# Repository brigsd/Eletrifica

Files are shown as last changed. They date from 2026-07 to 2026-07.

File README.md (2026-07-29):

# Controladora CNC / Laser com ESP32

> ### ▶ [**Abrir o visualizador 3D interativo**](https://brigsd.github.io/Eletrifica/)
> Gire a placa, oculte as peças que quiser pelo menu lateral e **dê dois cliques
> em qualquer componente** para ver o que ele faz e em quais nets ele está ligado.

Este repositório é a **engenharia reversa completa de uma placa de circuito
impresso**, feita a partir do único material disponível: o pacote Gerber que se
manda para a fábrica.

A placa é uma **controladora de CNC / gravadora a laser de dois eixos**: um
módulo ESP32 comanda dois drivers de passo A4988 e chaveia um laser por um
MOSFET. São 70,5 × 54,6 mm, duas camadas, 19 componentes e 43 nets.

Partindo só do Gerber, foram reconstruídos:

| | |
|---|---|
| **Netlist** | Todas as 43 ligações, conferidas por dois métodos independentes |
| **Esquemático** | Projeto KiCad que abre e edita, gerado por script a partir da netlist |
| **Layout** | Desenho das trilhas, pads e serigrafia das duas faces |
| **Modelo 3D** | A placa montada, com cada peça posicionada pelo Gerber |
| **Visualizador** | A página interativa publicada no GitHub Pages |
| **Análise** | Como o circuito funciona — e um defeito que ele tem |

E, no meio do caminho, **dois problemas apareceram** — um elétrico e um
mecânico. Ambos estão em [`docs/analise.md`](docs/analise.md).

---

## O visualizador 3D

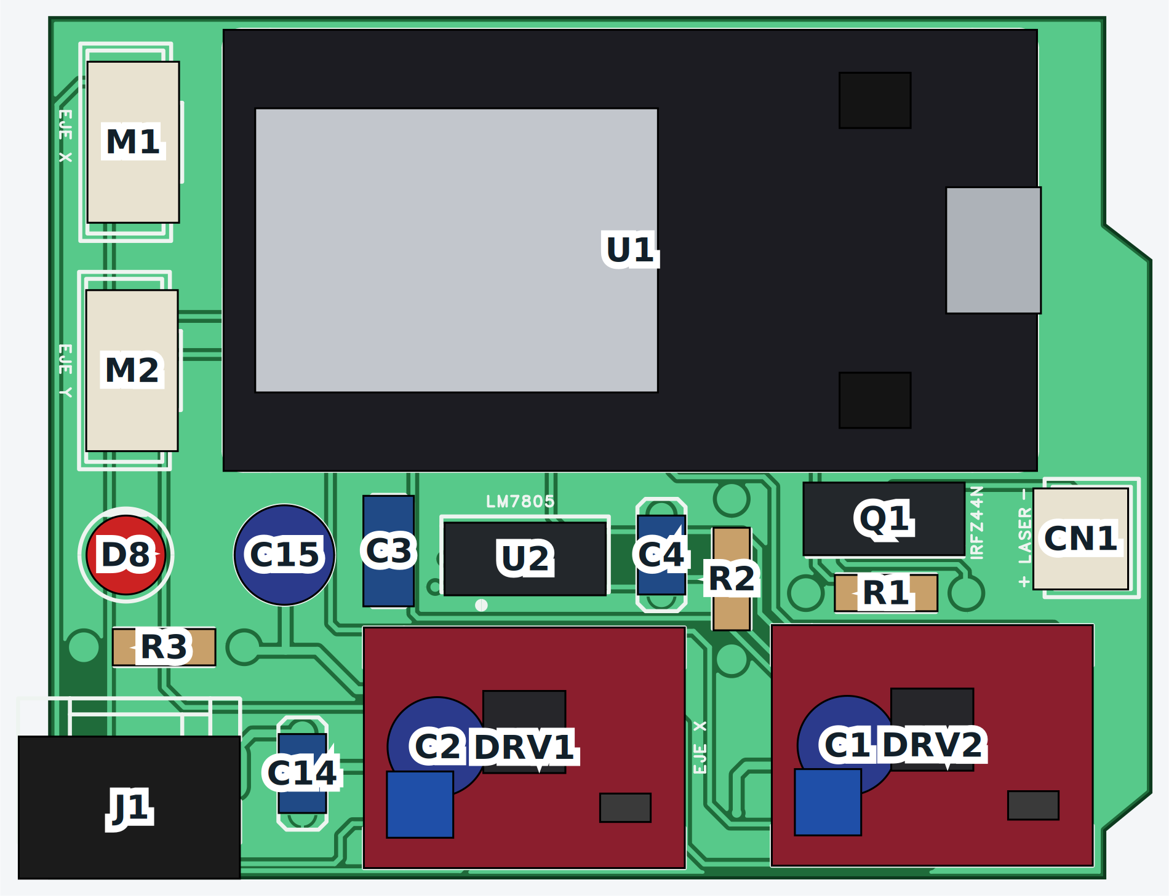
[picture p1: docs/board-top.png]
Visualizador (https://brigsd.github.io/Eletrifica/)


**→ [brigsd.github.io/Eletrifica](https://brigsd.github.io/Eletrifica/)**

- **Menu lateral** — liga e desliga cada peça, ou um grupo inteiro (Controle,
  Eixos, Alimentação, Laser). O botão *Placa* esconde a própria placa, o que
  deixa ver o que fica por baixo dos módulos.
- **Duplo clique numa peça** — abre para que ela serve, com a lista de
  pino → net daquele componente.
- **▲ vermelho** no menu marca as peças envolvidas no conflito de folga.

A página é estática e não depende de nada externo: o Three.js está versionado
em `web/`, junto com a geometria em `web/board.json`, que sai do mesmo modelo
que gera os desenhos impressos.

---

## Layout da placa

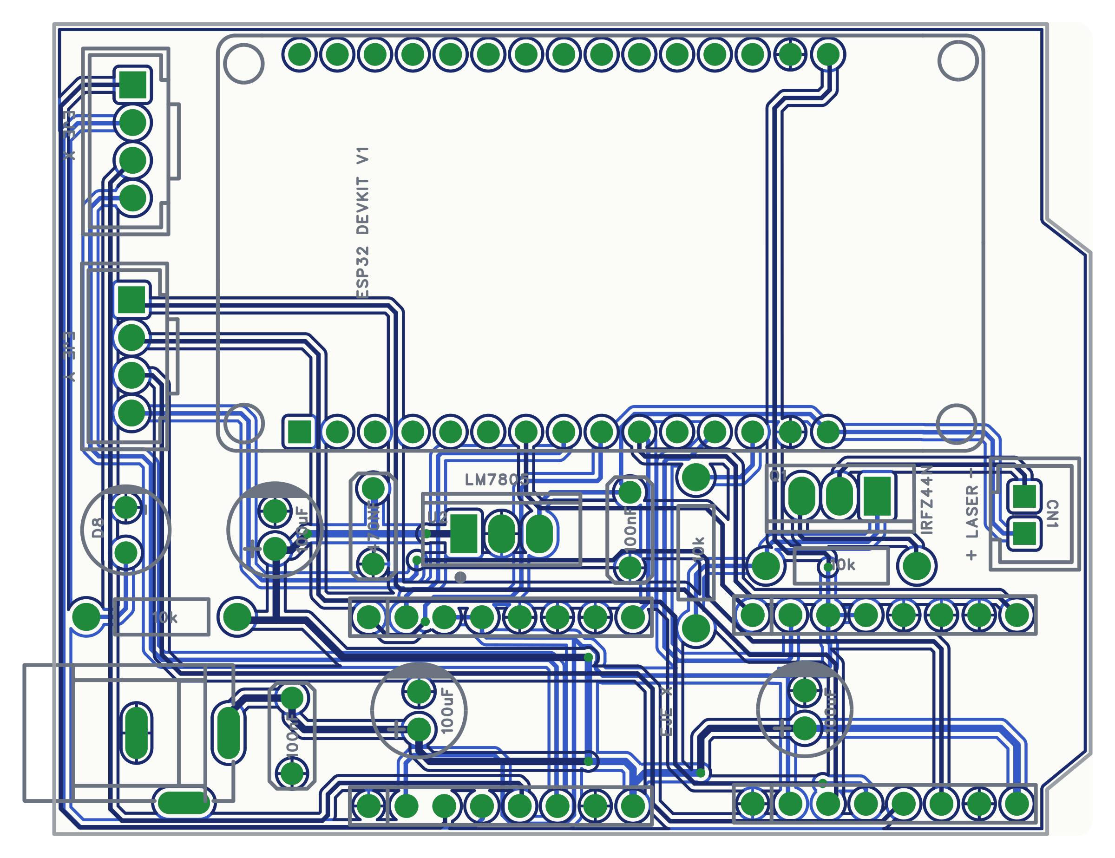
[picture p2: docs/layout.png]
Layout


Trilhas da face superior em azul-escuro, da face inferior em azul-claro, pads em
verde e serigrafia em cinza. Os planos de terra ficam ocultos por padrão para as
trilhas aparecerem; `--pour` desenha eles em tom claro.

```bash
python3 tools/render_layout.py --split    # layout.svg, layout-top.svg, layout-bottom.svg
```

Também são gravados os `.png` correspondentes.

## Vistas 3D

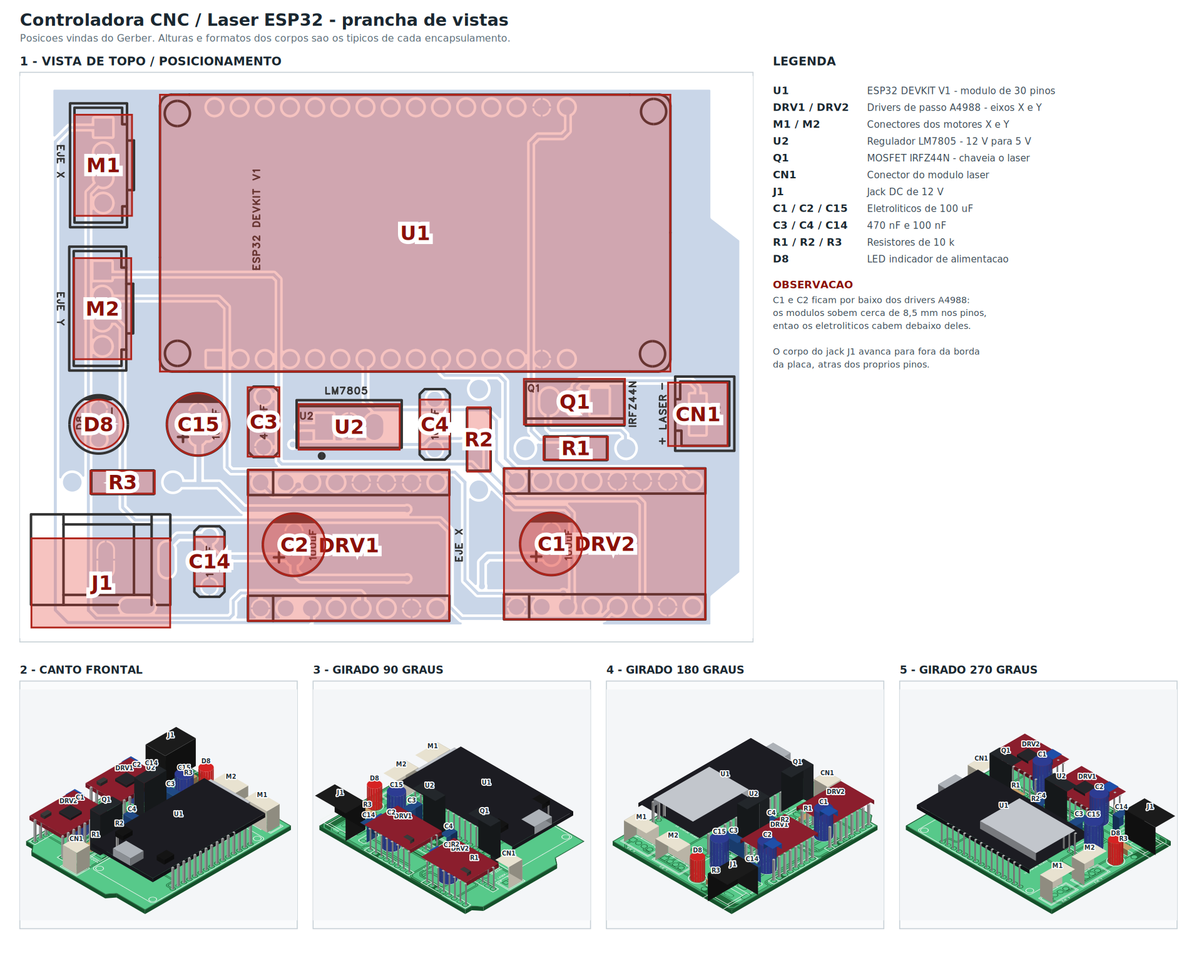
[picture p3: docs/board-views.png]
Prancha de vistas


Vista de topo com os corpos sobre a serigrafia (para conferir posicionamento) e
o mesmo conjunto visto de quatro ângulos.

```bash
python3 tools/render_3d.py --sheet --plan --views --steps
```

### Módulos como peças próprias

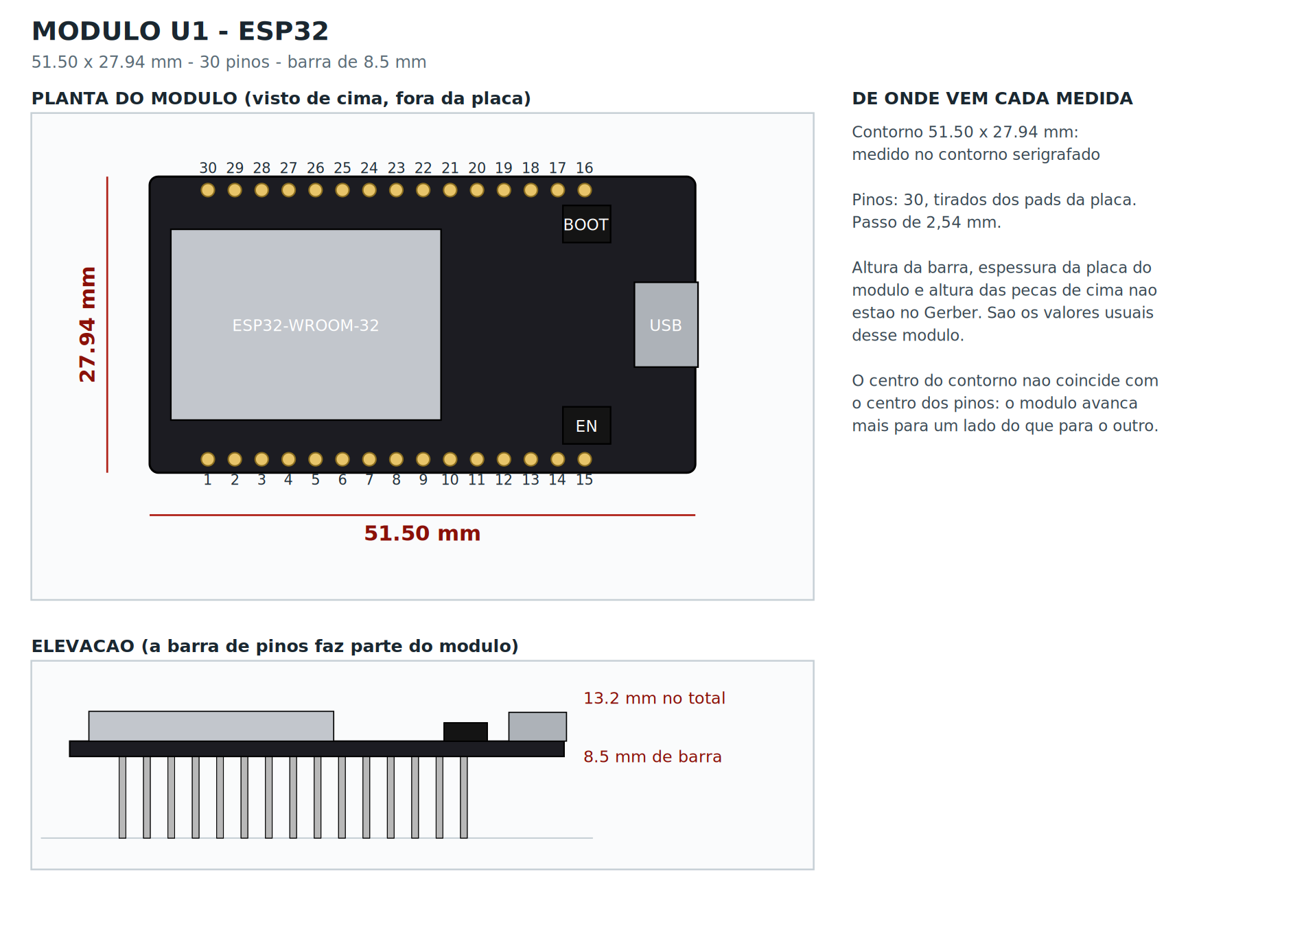
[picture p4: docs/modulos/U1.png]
Módulo ESP32


Os três módulos (ESP32 e os dois A4988) são modelados como peças em si: contorno
próprio, barra de pinos própria e o que fica em cima deles. O contorno do ESP32
**foi medido no desenho que a placa-mãe carrega na serigrafia** para ele —
51,50 × 27,94 mm, que é a medida real do DevKit V1, e cujo centro fica 2,5 mm
deslocado do centro dos pinos. `docs/modulos/` traz uma página por módulo.

Modelar os módulos direito fez aparecer um conflito mecânico: os eletrolíticos
C1 e C2 ficam debaixo dos drivers e, pelas alturas usuais, não passam no vão.
Ver [`docs/analise.md`](docs/analise.md).

### Conferência peça por peça

`--steps` grava `docs/posicionamento/`: uma página por peça, começando pela placa
nua. Cada página mostra a **placa sozinha mais uma única peça**, para conferir a
posição sem as outras atrapalhando — vista de topo sobre a serigrafia, uma
perspectiva, e as **quatro vistas laterais ortográficas** (frente, trás, esquerda,
direita), com a câmera na altura da placa. São **duas vistas de topo**: uma com a
peça sólida, como a placa montada se vê de cima, e outra em raio X sobre a
serigrafia, para conferir se o corpo cai em cima do próprio contorno. Nas laterais a altura sai verdadeira,
coisa que nenhuma vista isométrica dá. As demais peças ficam fantasmas em 12 %
só como referência.

Foi assim que apareceram os dois detalhes anotados na prancha: o eletrolítico
por baixo do driver A4988 e o corpo do jack passando da borda.

As **posições** de todas as peças saem do Gerber, tiradas do centro dos pads de
cada uma. As **alturas e formatos dos corpos não saem do Gerber** — um Gerber não
tem modelo 3D — então são as dimensões típicas de cada encapsulamento, listadas
em `BODIES` no script. O desenho serve para entender a placa, não para
verificação mecânica.

## Esquemático

Esquemático

## O que é a placa

Controladora de **CNC / gravadora a laser de 2 eixos**: um módulo ESP32 DEVKIT V1
comanda dois drivers de passo tipo A4988 (eixos X e Y) e chaveia um laser por um
MOSFET. Alimentação de 12 V com regulação para 5 V por LM7805.

70,5 × 54,6 mm · 2 camadas · 19 componentes · 43 nets

## Arquivos

| Caminho | Conteúdo |
|---|---|
| `hardware/esp32-cnc-laser.kicad_sch` | Esquemático KiCad (abre no KiCad 7+) |
| `hardware/esp32-cnc-laser.kicad_pro` | Projeto KiCad |
| `docs/board-views.svg` · `.png` | Prancha: topo + quatro ângulos |
| `docs/board-top.svg` · `.png` | Vista de topo com as peças sólidas |
| `docs/board-plan-check.*` | Vista de topo em raio X sobre a serigrafia |
| `docs/posicionamento/` | Uma página por peça: 2 topos, perspectiva e 4 laterais |
| `docs/modulos/` | Uma página por módulo, com as medidas e a pinagem |
| `docs/board-3d-000/090/180/270.*` | Cada ângulo separado |
| `docs/layout.svg` · `.png` | Desenho do layout (as duas faces) |
| `docs/layout-top.*` · `layout-bottom.*` | Layout de cada face separadamente |
| `docs/esp32-cnc-laser.svg` · `.pdf` | Esquemático renderizado |
| `docs/analise.md` | Como o circuito funciona e o que há de errado nele |
| `docs/bom.md` | Lista de materiais |
| `docs/netlist.md` | Tabela de todos os nets |
| `index.html` · `web/` | O visualizador 3D publicado no GitHub Pages |
| `gerber/` | Pacote Gerber original, que é a fonte de tudo |
| `THIRD_PARTY.md` | Código de terceiros no repositório, com versão e licença |
| `tools/` | Scripts que geram e conferem o esquemático |

## De onde veio cada informação

**As conexões** vêm de `gerber/FlyingProbeTesting.json`, um arquivo do pacote
Gerber que lista o net de cada pad da placa. Nada de conectividade foi inferido.

**Os valores e part numbers** foram lidos da serigrafia
(`gerber/Gerber_TopSilkscreenLayer.GTO`), renderizada a partir do Gerber.

**A pinagem** dos módulos ESP32 e A4988 foi deduzida da netlist e confere com a
pinagem padrão desses módulos em todas as 30 e 16 ligações.

## Como isso foi verificado

O esquemático não é um desenho "que parece certo" — ele é conferido por duas
verificações automáticas:

```bash
python3 tools/verify_netlist.py   # esquemático  x  netlist da placa
python3 tools/check_copper.py     # geometria do cobre  x  netlist da placa
```

**`verify_netlist.py`** exporta a netlist do `.kicad_sch` com o `kicad-cli` e
compara net a net com a da placa. Resultado atual: **22 de 22 nets idênticos**,
sem sobra nem falta.

**`check_copper.py`** é independente do arquivo de netlist: rasteriza as duas
camadas de cobre usando as aberturas do próprio Gerber, rotula as ilhas de cobre
conectadas e une as faces nos furos metalizados e nas 9 vias. Ele só usa
coordenadas, nunca nomes de net. Resultado atual: **43 ilhas para os 43 nets, com
0 falsos cortes e 0 falsos curtos**.

## Um defeito encontrado na placa

O **source do Q1 (IRFZ44N) não chega ao GND** em nenhuma das duas camadas. O net
tem só dois pads: o pino 3 do Q1 e o pino 1 do R1. Sem esse retorno o MOSFET não
conduz e **o laser nunca acende**, independente do firmware.

Os dois métodos de verificação acima concordam nisso. Detalhes e as demais
observações de projeto em [`docs/analise.md`](docs/analise.md).

## Regenerar

Precisa de KiCad 7+ (`kicad-cli`) e das dependências em `requirements.txt`.

```bash
pip install -r requirements.txt

python3 tools/render_layout.py --split   # desenhos do layout
python3 tools/export_web.py         # dados do visualizador 3D
python3 tools/gen_schematic.py      # escreve hardware/esp32-cnc-laser.kicad_sch
python3 tools/gen_docs.py           # escreve docs/bom.md e docs/netlist.md
kicad-cli sch export svg --output docs hardware/esp32-cnc-laser.kicad_sch
kicad-cli sch export pdf --output docs/esp32-cnc-laser.pdf hardware/esp32-cnc-laser.kicad_sch
```

O esquemático é **gerado** a partir do Gerber, não desenhado à mão:
`gen_schematic.py` lê a netlist da placa e emite o `.kicad_sch`. Corrigir a placa
é mudar o Gerber e rodar de novo.

## Código de terceiros

Duas coisas aqui não são deste projeto: o **three.js** (MIT), versionado em
`web/` para o visualizador não depender de CDN, e **doze símbolos do KiCad**
(CC-BY-SA 4.0 com exceção), embutidos no `.kicad_sch` para ele abrir em
qualquer máquina. Detalhes e textos de licença em
[`THIRD_PARTY.md`](THIRD_PARTY.md).

## Licença

**MIT** — ver [`LICENSE`](LICENSE).

Cobre o que foi criado aqui: os scripts, o visualizador, os desenhos e a
documentação. **Não cobre o `gerber/`**, que é o projeto original da placa e
pertence a quem a desenhou — ele está aqui como material de origem da
engenharia reversa.

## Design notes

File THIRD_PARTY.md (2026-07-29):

# Código de terceiros

Duas coisas neste repositório não são deste projeto: a biblioteca 3D usada pelo
visualizador e alguns símbolos de esquemático do KiCad. Estão listadas aqui com
a versão e a licença de cada uma.

As bibliotecas Python usadas pelos scripts (`gerbonara`, `cairosvg`, `numpy`,
`scipy`, `pillow`) **não** estão no repositório — vêm por `pip` a partir do
`requirements.txt` e não foram copiadas para cá.

---

## 1. three.js — em `web/`

| | |
|---|---|
| Projeto | [three.js](https://threejs.org/) |
| Versão | r128 (`three@0.128.0`) |
| Arquivos | `web/three.min.js` · `web/OrbitControls.js` |
| Licença | MIT |

`OrbitControls.js` vem de `examples/js/controls/` do mesmo pacote.

**Por que está versionado aqui em vez de vir de CDN:** a página não busca nada
de fora. Não quebra se um CDN sair do ar ou mudar de política, funciona offline,
e o que foi testado é exatamente o que vai para o ar.

### Licença MIT

```
The MIT License

Copyright © 2010-2021 three.js authors

Permission is hereby granted, free of charge, to any person obtaining a copy
of this software and associated documentation files (the "Software"), to deal
in the Software without restriction, including without limitation the rights
to use, copy, modify, merge, publish, distribute, sublicense, and/or sell
copies of the Software, and to permit persons to whom the Software is
furnished to do so, subject to the following conditions:

The above copyright notice and this permission notice shall be included in
all copies or substantial portions of the Software.

THE SOFTWARE IS PROVIDED "AS IS", WITHOUT WARRANTY OF ANY KIND, EXPRESS OR
IMPLIED, INCLUDING BUT NOT LIMITED TO THE WARRANTIES OF MERCHANTABILITY,
FITNESS FOR A PARTICULAR PURPOSE AND NONINFRINGEMENT. IN NO EVENT SHALL THE
AUTHORS OR COPYRIGHT HOLDERS BE LIABLE FOR ANY CLAIM, DAMAGES OR OTHER
LIABILITY, WHETHER IN AN ACTION OF CONTRACT, TORT OR OTHERWISE, ARISING FROM,
OUT OF OR IN CONNECTION WITH THE SOFTWARE OR THE USE OR OTHER DEALINGS IN
THE SOFTWARE.
```

---

## 2. Símbolos do KiCad — dentro de `hardware/esp32-cnc-laser.kicad_sch`

| | |
|---|---|
| Projeto | [KiCad Symbols](https://kicad.github.io/symbols/) |
| Copyright | KiCad Community |
| Licença | CC-BY-SA 4.0 **com exceção** (texto abaixo) |

Um arquivo `.kicad_sch` sempre carrega dentro de si a definição dos símbolos que
usa, na seção `lib_symbols`. `tools/gen_schematic.py` copia essas definições da
instalação local do KiCad para o arquivo gerado — é o que faz o esquemático
abrir em qualquer máquina, sem depender de quais bibliotecas estão instaladas.

**Doze símbolos vêm do KiCad:**

`Device:R` · `Device:C` · `Device:C_Polarized` · `Device:LED` ·
`Device:Q_NMOS_GDS` · `Regulator_Linear:LM7805_TO220` ·
`Connector_Generic:Conn_01x02` · `Conn_01x03` · `Conn_01x04` ·
`power:+12V` · `power:+5V` · `power:GND`

**Dois foram desenhados para este projeto**, porque não existem na biblioteca do
KiCad — são gerados por `rect_symbol()` em `tools/gen_schematic.py`:

`Module:ESP32_DEVKIT_V1` (30 pinos) · `Module:A4988` (16 pinos)

### A exceção da licença

A CC-BY-SA normalmente exigiria que trabalhos derivados fossem publicados sob a
mesma licença. A biblioteca do KiCad traz uma renúncia explícita a isso para
projetos eletrônicos:

> To the extent that the creation of electronic designs that use 'Licensed
> Material' can be considered to be 'Adapted Material', then the copyright
> holder waives article 3 of the license with respect to these designs and any
> generated files which use data provided as part of the 'Licensed Material'.

Ou seja: usar esses símbolos **não obriga** este projeto a adotar CC-BY-SA.

---

## Licença deste projeto

**MIT** — ver [`LICENSE`](LICENSE).

Ela cobre o que foi criado aqui: os scripts em `tools/`, o visualizador, e os
desenhos e documentos gerados em `docs/` e `hardware/`.

**Não cobre o `gerber/`.** Aquele pacote é o projeto original da placa e
pertence a quem a desenhou — está no repositório como material de origem da
engenharia reversa. O `LICENSE` diz isso explicitamente.

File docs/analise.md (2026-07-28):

# Análise do circuito

Placa: **controladora CNC / gravadora a laser de 2 eixos com ESP32**, dupla face,
70,5 × 54,6 mm, 19 componentes, 43 nets.

---

## Como o circuito funciona

### 1. Entrada e regulação

O jack `DC_CARGADOR` traz **12 V**, que alimentam diretamente o `VMOT` dos dois
drivers de passo. O trilho de 12 V tem três eletrolíticos de 100 µF (C1, C2, C15)
e um cerâmico de 100 nF (C14).

O **LM7805** (U2) derruba 12 V para **5 V**, com C3 (470 nF) na entrada e C4
(100 nF) na saída. O trilho de 5 V alimenta o `VIN` do ESP32 e o positivo do laser.

O **3,3 V** não é gerado na placa: sai do regulador interno do próprio módulo
ESP32 (pino 3V3) e alimenta o `VDD` lógico dos dois drivers.

`D8` + `R3` (10 k) formam o indicador de alimentação, ligado no trilho de 12 V.

### 2. Controle

O **ESP32 DEVKIT V1** usa 6 dos seus 30 pinos:

| Pino | GPIO | Sinal |
|---|---|---|
| 8  | GPIO25 | `STEP` — eixo X |
| 9  | GPIO26 | `DIR` — eixo X |
| 12 | GPIO12 | `STEP_2` — eixo Y |
| 7  | GPIO33 | `DIR_2` — eixo Y |
| 10 | GPIO27 | `EN` — habilita **os dois** drivers |
| 13 | GPIO13 | PWM do laser |

Os outros 24 pinos ficam sem ligação.

### 3. Drivers de passo

Dois módulos de 16 pinos tipo **A4988**, um por eixo. A configuração é idêntica
nos dois e foi lida da netlist:

- `MS1`, `MS2`, `MS3` → **GND** ⇒ modo **passo inteiro**, sem micropasso
- `RESET` + `SLEEP` → **3,3 V** ⇒ driver habilitado (ligação padrão)
- `VMOT` → 12 V, `VDD` → 3,3 V
- Bobinas `1A`/`1B` e `2A`/`2B` vão para os conectores `EJE X` e `EJE Y`

### 4. Saída do laser

`GPIO13` → `R2` (10 k) → gate do **IRFZ44N** (Q1). `R1` (10 k) liga o gate ao
source. O dreno do Q1 é o `LASER_NEG`, que vai ao pino 1 do `CN1`; o pino 2 do
`CN1` é o **+5 V**. Ou seja, o laser é alimentado em 5 V e o MOSFET chaveia o
lado negativo.

---

## Achados

### 🔴 1. O source do Q1 não tem retorno para o GND

**Este é um defeito de projeto da placa, não do esquemático.**

O net do source do Q1 (chamado `$1N1796` no arquivo original, renomeado aqui para
`SRC_Q1`) contém **exatamente dois pads**: `Q1` pino 3 e `R1` pino 1. Ele não
toca o GND em nenhuma das duas camadas de cobre, nem através de via.

Sem esse retorno o IRFZ44N não tem circuito de dreno-source fechado: **o laser
nunca acende**, independentemente do que o firmware faça com o GPIO13.

Isso foi verificado por dois caminhos independentes, que concordam:

1. **`FlyingProbeTesting.json`** — o arquivo de teste que acompanha o Gerber,
   gerado pelo CAM a partir da placa, lista o net de cada pad. `SRC_Q1` tem 2 pads.
2. **Geometria do cobre** (`tools/check_copper.py`) — rasteriza as duas camadas
   a partir das aberturas do Gerber, rotula as ilhas de cobre conectadas e une as
   faces nos furos metalizados e nas 9 vias. Esse método **não lê nenhum nome de
   net**, só coordenadas. Resultado: 43 ilhas para os 43 nets da placa, com
   **0 falsos cortes e 0 falsos curtos**, e a ilha do `Q1` pino 3 contém apenas
   `Q1_3` e `R1_1`.

Como o segundo método reproduz a netlist inteira sem um único erro, o resultado
sobre o `SRC_Q1` tem o mesmo grau de confiança que o resto da netlist.

**Correção:** ligar o pino 3 (source) do Q1 ao GND.

> Vale confirmar com um multímetro em modo continuidade entre o pino 3 do Q1 e
> qualquer ponto de GND antes de alterar a placa — é um teste de 10 segundos.

### 🟡 2. O IRFZ44N não é um MOSFET de nível lógico

Observação de datasheet, não da netlist. O IRFZ44N tem `Vgs(th)` entre 2,0 e
4,0 V e o `Rds(on)` de 17,5 mΩ é especificado com **`Vgs` = 10 V**. Acionado pelos
3,3 V de um GPIO do ESP32, ele opera perto do limiar: conduz pouco e esquenta.

Mesmo depois de corrigir o problema 1, vale trocar por um MOSFET de nível lógico
(IRLZ44N, IRL540N, AOD4184) ou acrescentar um driver de gate.

### 🟡 3. R2 = 10 k em série com o gate

O IRFZ44N tem cerca de 1,5 nF de capacitância de entrada. Com 10 k em série a
constante de tempo fica na casa de 15 µs. Serve para ligar/desligar, mas limita
bastante o PWM — o que é justamente o modo como se controla potência de laser.
Algo entre 100 Ω e 220 Ω seria mais adequado.

### 🟡 4. O laser é alimentado pelo LM7805

O `CN1` pino 2 está no trilho de 5 V, saída do LM7805. A queda é de 7 V (12 → 5),
então **cada 100 mA de laser dissipam 0,7 W no regulador**. Um módulo laser
comum de 500 mA levaria o LM7805 a 3,5 W — muito além do que um TO-220 sem
dissipador aguenta. Não há área de dissipação no layout.

### 🟡 5. Trilho de 5 V sem capacitor de reservatório

Os três eletrolíticos de 100 µF estão todos no trilho de 12 V. O 5 V tem apenas
C4 = 100 nF. Com o ESP32 fazendo picos de corrente de Wi-Fi nesse mesmo trilho,
convém acrescentar um eletrolítico de 100–470 µF na saída do LM7805.

### 🟡 6. GPIO12 é pino de strapping

`STEP_2` (eixo Y) está no **GPIO12**, que no ESP32 é o strapping `MTDI`: se
estiver em nível alto no reset, ele configura o `VDD_SDIO` para 1,8 V e o módulo
não dá boot. A entrada `STEP` do A4988 é de alta impedância e não deve puxar o
pino para cima, então na prática deve funcionar — mas se a placa apresentar boot
intermitente, é o primeiro lugar para olhar.

### 🟡 7. Os eletrolíticos ficam debaixo dos drivers — e talvez não caibam

Isto apareceu no desenho 3D, não na netlist. `C1` e `C2` (100 µF) estão **dentro
da área ocupada pelos módulos A4988**, que ficam suspensos sobre a barra de pinos.

| | |
|---|---|
| Altura de um 100 µF radial de 6,3 mm | ~11 mm de corpo, 12,6 mm a partir do topo da placa |
| Face inferior do A4988 sobre barra fêmea de 8,5 mm | 10,1 mm |
| **Folga** | **−2,5 mm** |

Ou seja, pelas dimensões usuais desses dois componentes, **o capacitor bate no
módulo**. A altura máxima que passa nesse vão é de cerca de 8,5 mm de corpo.

**Atenção ao grau de confiança:** as duas medidas são valores típicos, não saem
do Gerber — o Gerber não guarda altura. O que o Gerber prova é só a **posição**:
os capacitores estão mesmo debaixo dos drivers. Se a placa já foi montada e
funciona, provavelmente foram usados capacitores baixos, barra mais alta, ou os
capacitores foram deitados. Vale medir antes de comprar componente.

Rodar `python3 tools/render_3d.py --steps` imprime essa conferência de folga.

### 🔵 8. Observações menores

- `R3` = 10 k no LED de 12 V dá cerca de **1 mA** — funciona com LED moderno, mas fica fraco.
- O pino 3 do jack DC (contato de comutação) não está ligado.
- `EN` é comum aos dois drivers: não dá para desabilitar um eixo isoladamente.
- Modo passo inteiro fixo: para mudar micropasso é preciso cortar as ligações de MS1–MS3 para o GND.
- A corrente das bobinas é ajustada pelo trimpot `Vref` de cada módulo A4988, fora do escopo da placa.

---

## Confiança de cada informação

| Informação | Origem | Confiança |
|---|---|---|
| Conexões (todos os 43 nets) | `FlyingProbeTesting.json` + geometria do cobre, conferidos entre si | Verificado por 2 métodos |
| Valores e part numbers | Serigrafia (`Gerber_TopSilkscreenLayer.GTO`) | Lido diretamente |
| Polaridade de D8 e dos eletrolíticos | Chanfro e marca `+` na serigrafia | Lido diretamente |
| Pinagem do A4988 e do ESP32 | Deduzida da netlist e conferida contra a pinagem padrão dos módulos | Alta — as 16 e 30 ligações batem sem exceção |
| Achados 2 a 6 | Datasheets dos componentes | Análise de projeto, não medição |

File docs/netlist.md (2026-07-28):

# Netlist da placa

Extraida de `gerber/FlyingProbeTesting.json`, que traz o net de cada pad.
Os nets `$1N1790`, `$1N1796` e `$1N2332` nao tem nome no arquivo original;
foram renomeados para `GATE_Q1`, `SRC_Q1` e `LED_A`.

| Net | Pinos | Ligacoes |
|-----|---|---|
| `GND` | 21 | C1.2, C14.2, C15.2, C2.2, C3.2, C4.2, D8.2, DRV1.10, DRV1.16, DRV1.5, DRV1.6, DRV1.7, DRV2.10, DRV2.16, DRV2.5, DRV2.6, DRV2.7, J1.2, U1.14, U1.17, U2.2 |
| `+12V` | 10 | C1.1, C14.1, C15.1, C2.1, C3.1, DRV1.9, DRV2.9, J1.1, R3.2, U2.1 |
| `+3V3` | 7 | DRV1.15, DRV1.3, DRV1.4, DRV2.15, DRV2.3, DRV2.4, U1.16 |
| `+5V` | 4 | C4.1, CN1.2, U1.15, U2.3 |
| `EN` | 3 | DRV1.8, DRV2.8, U1.10 |
| `GATE_Q1` | 3 | Q1.1, R1.2, R2.1 |
| `1A` | 2 | DRV1.13, M1.2 |
| `1A_2` | 2 | DRV2.13, M2.2 |
| `1B` | 2 | DRV1.14, M1.1 |
| `1B_2` | 2 | DRV2.14, M2.1 |
| `2A` | 2 | DRV1.12, M1.3 |
| `2A_2` | 2 | DRV2.12, M2.3 |
| `2B` | 2 | DRV1.11, M1.4 |
| `2B_2` | 2 | DRV2.11, M2.4 |
| `D13` | 2 | R2.2, U1.13 |
| `DIR` | 2 | DRV1.1, U1.9 |
| `DIR_2` | 2 | DRV2.1, U1.7 |
| `LASER_NEG` | 2 | CN1.1, Q1.2 |
| `LED_A` | 2 | D8.1, R3.1 |
| `SRC_Q1` | 2 | Q1.3, R1.1 |
| `STEP` | 2 | DRV1.2, U1.8 |
| `STEP_2` | 2 | DRV2.2, U1.12 |

Pinos do ESP32 sem ligacao: 20 de 30.

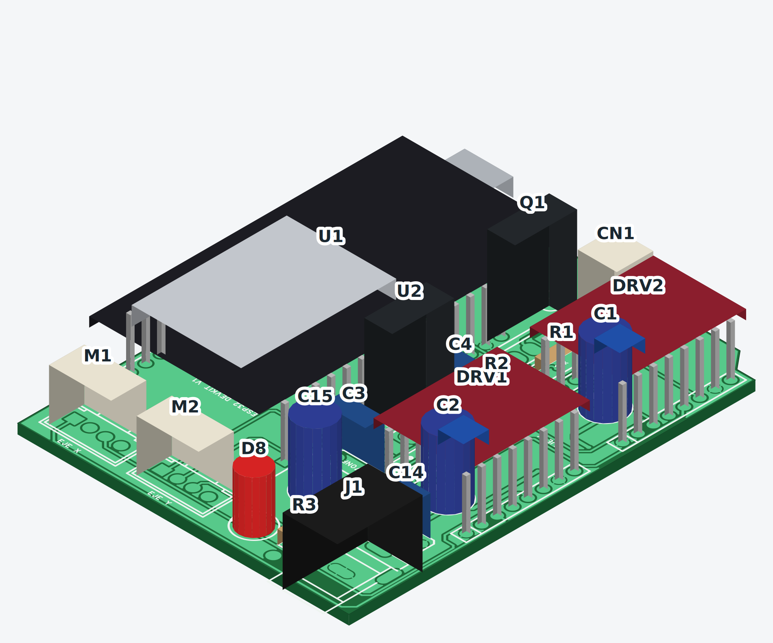
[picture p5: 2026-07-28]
docs/board-3d-180.png

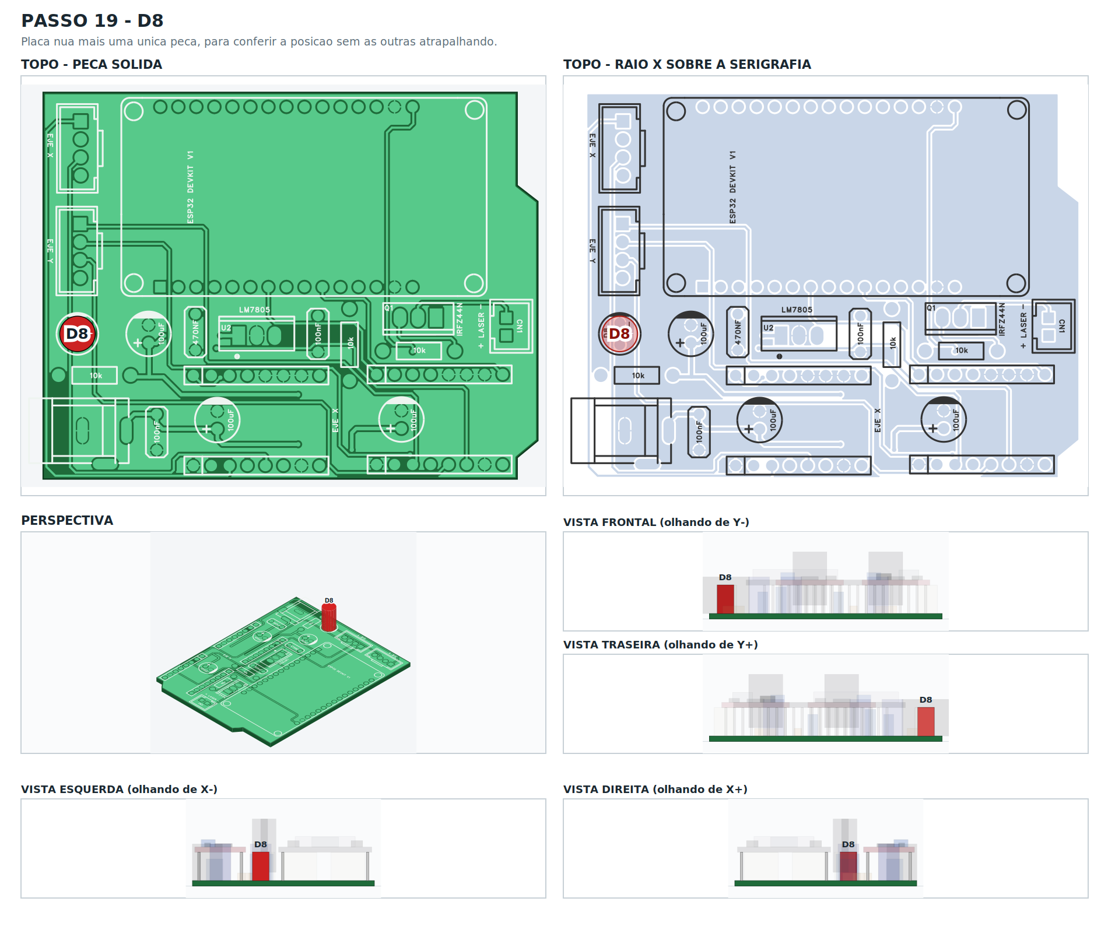
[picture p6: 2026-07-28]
docs/posicionamento/19-D8.png

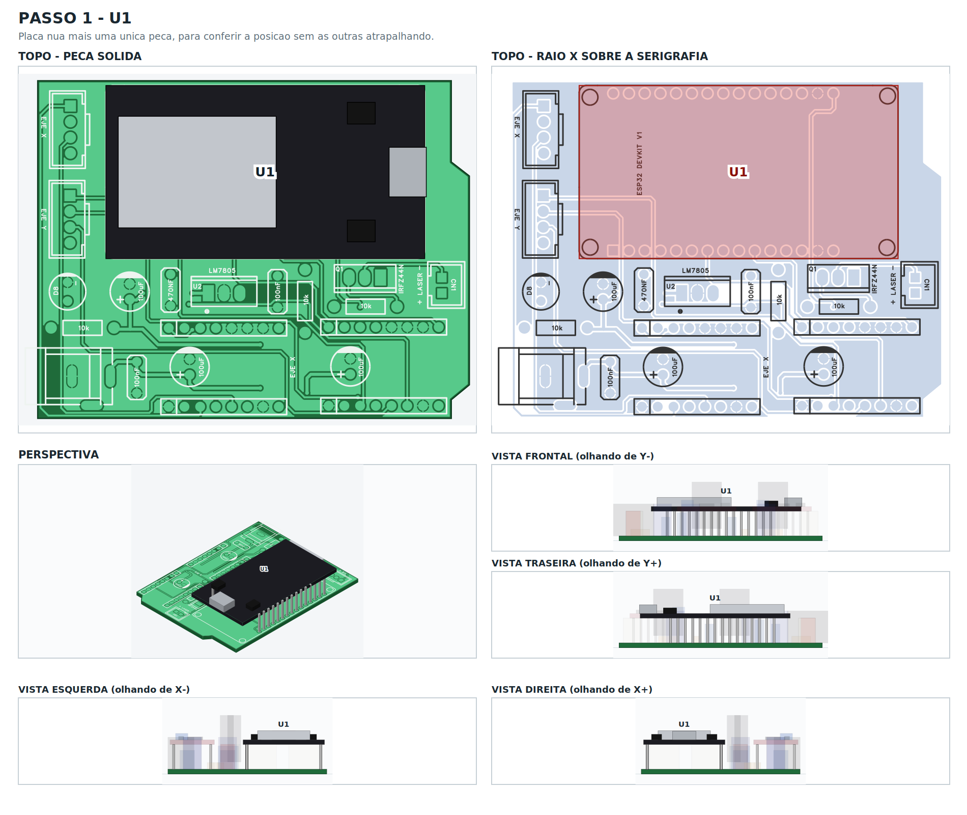
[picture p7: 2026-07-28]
docs/posicionamento/01-U1.png

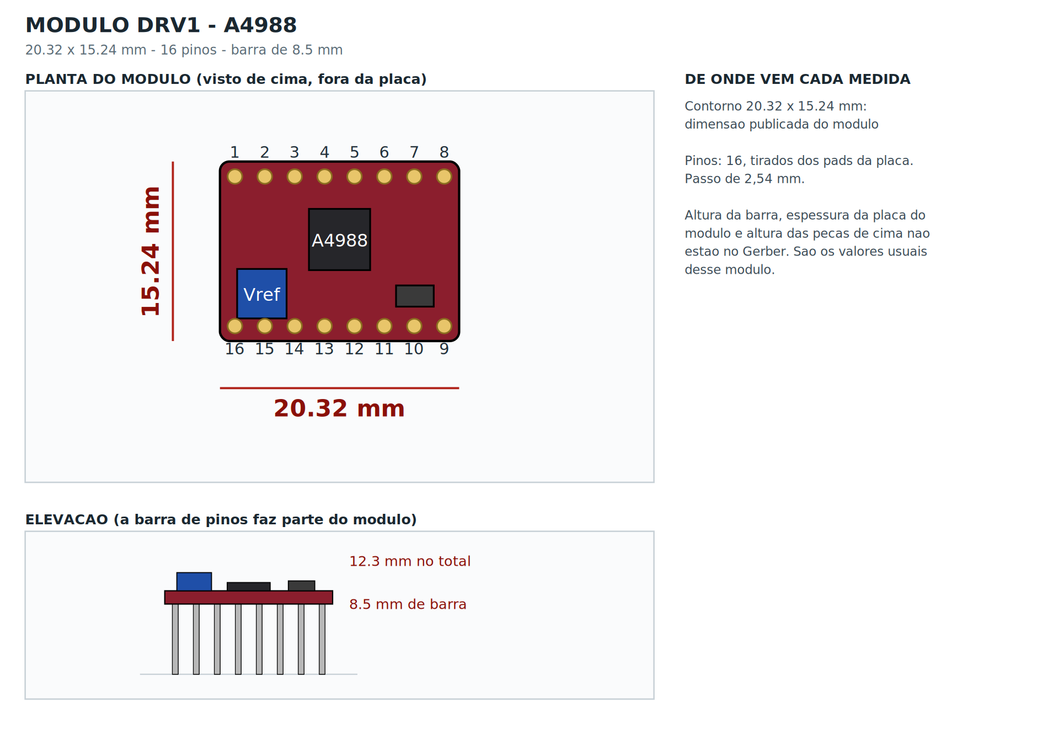
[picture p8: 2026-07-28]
docs/modulos/DRV1.png

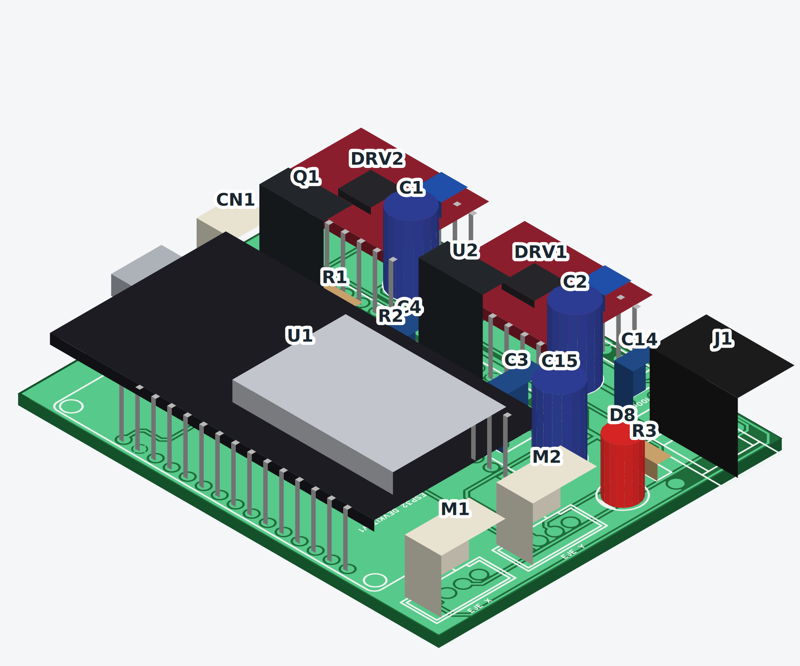
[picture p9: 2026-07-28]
docs/board-3d-270.png

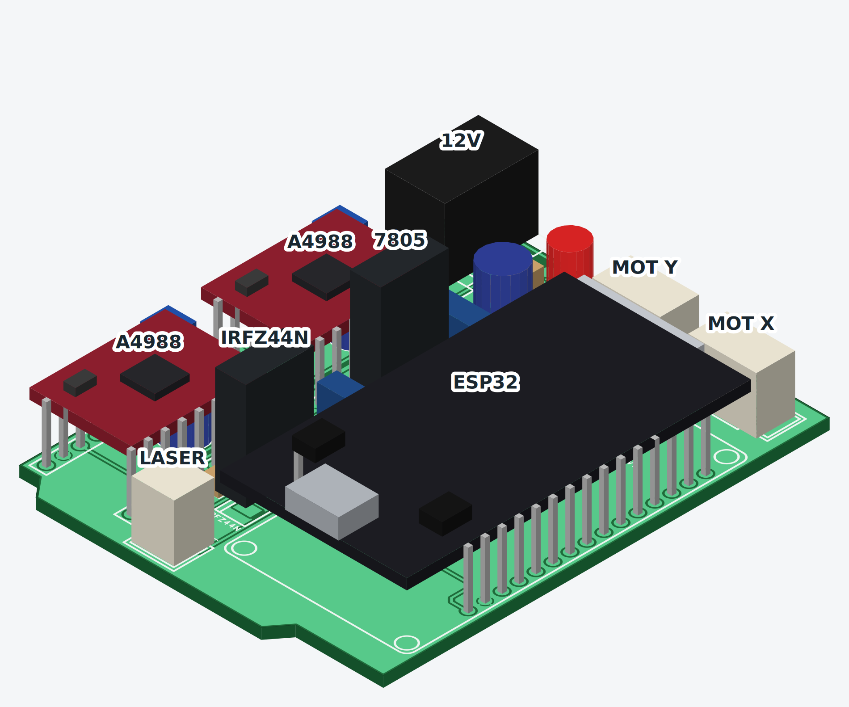
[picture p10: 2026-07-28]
docs/board-3d.png

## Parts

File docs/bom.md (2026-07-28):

# Lista de materiais

Extraida da serigrafia da placa (`Gerber_TopSilkscreenLayer.GTO`).

| Ref | Valor / part number | Nome na serigrafia | Pinos | Funcao |
|-----|---|---|---|---|
| J1 | Jack DC 12V | `DC_CARGADOR` | 3 | Jack DC de alimentacao (12 V). O pino 3 e o terminal de comutacao do jack e nao esta ligado. |
| U2 | LM7805 | `U2` | 3 | Regulador linear 12 V -> 5 V. Alimenta o ESP32 (VIN) e o laser. |
| C1 | 100uF | `C1` | 2 | Reservatorio no trilho de 12 V. |
| C2 | 100uF | `C2` | 2 | Reservatorio no trilho de 12 V. |
| C15 | 100uF | `C15` | 2 | Reservatorio na entrada do regulador. |
| C14 | 100nF | `C14` | 2 | Desacoplamento no trilho de 12 V. |
| C3 | 470nF | `C3` | 2 | Capacitor de entrada do LM7805. |
| C4 | 100nF | `C4` | 2 | Capacitor de saida do LM7805. |
| R3 | 10k | `R3` | 2 | Resistor serie do LED indicador. Com 12 V da cerca de 1 mA. |
| D8 | LED | `D8` | 2 | LED indicador de alimentacao. Pad 1 e o anodo na placa. |
| U1 | ESP32 DEVKIT V1 | `ESP32 DEVKIT V1` | 30 | Modulo ESP32 DEVKIT V1 (30 pinos). Gera STEP/DIR/EN e o PWM do laser. |
| DRV1 | A4988 - eixo X | `EJE X` | 16 | Driver de passo do eixo X. MS1-MS3 em GND e RESET+SLEEP em 3V3. |
| DRV2 | A4988 - eixo Y | `XA2_EJE_Y` | 16 | Driver de passo do eixo Y. Mesma configuracao do eixo X. |
| M1 | Motor X | `EJE X` | 4 | Conector do motor de passo do eixo X (bobinas 1A/1B e 2A/2B). |
| M2 | Motor Y | `EJE Y` | 4 | Conector do motor de passo do eixo Y. |
| R2 | 10k | `R2` | 2 | Resistor serie no gate do Q1, vindo do GPIO13. |
| R1 | 10k | `R1` | 2 | Resistor de gate para source do Q1. |
| Q1 | IRFZ44N | `Q1` | 3 | MOSFET canal N que chaveia o lado negativo do laser. |
| CN1 | LASER | `CN1` | 2 | Conector do modulo laser. O positivo vem do trilho de 5 V. |

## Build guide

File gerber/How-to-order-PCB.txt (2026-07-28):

How to Order PCB

Please refer to:
https://prodocs.easyeda.com/en/pcb/order-order-pcb/index.html

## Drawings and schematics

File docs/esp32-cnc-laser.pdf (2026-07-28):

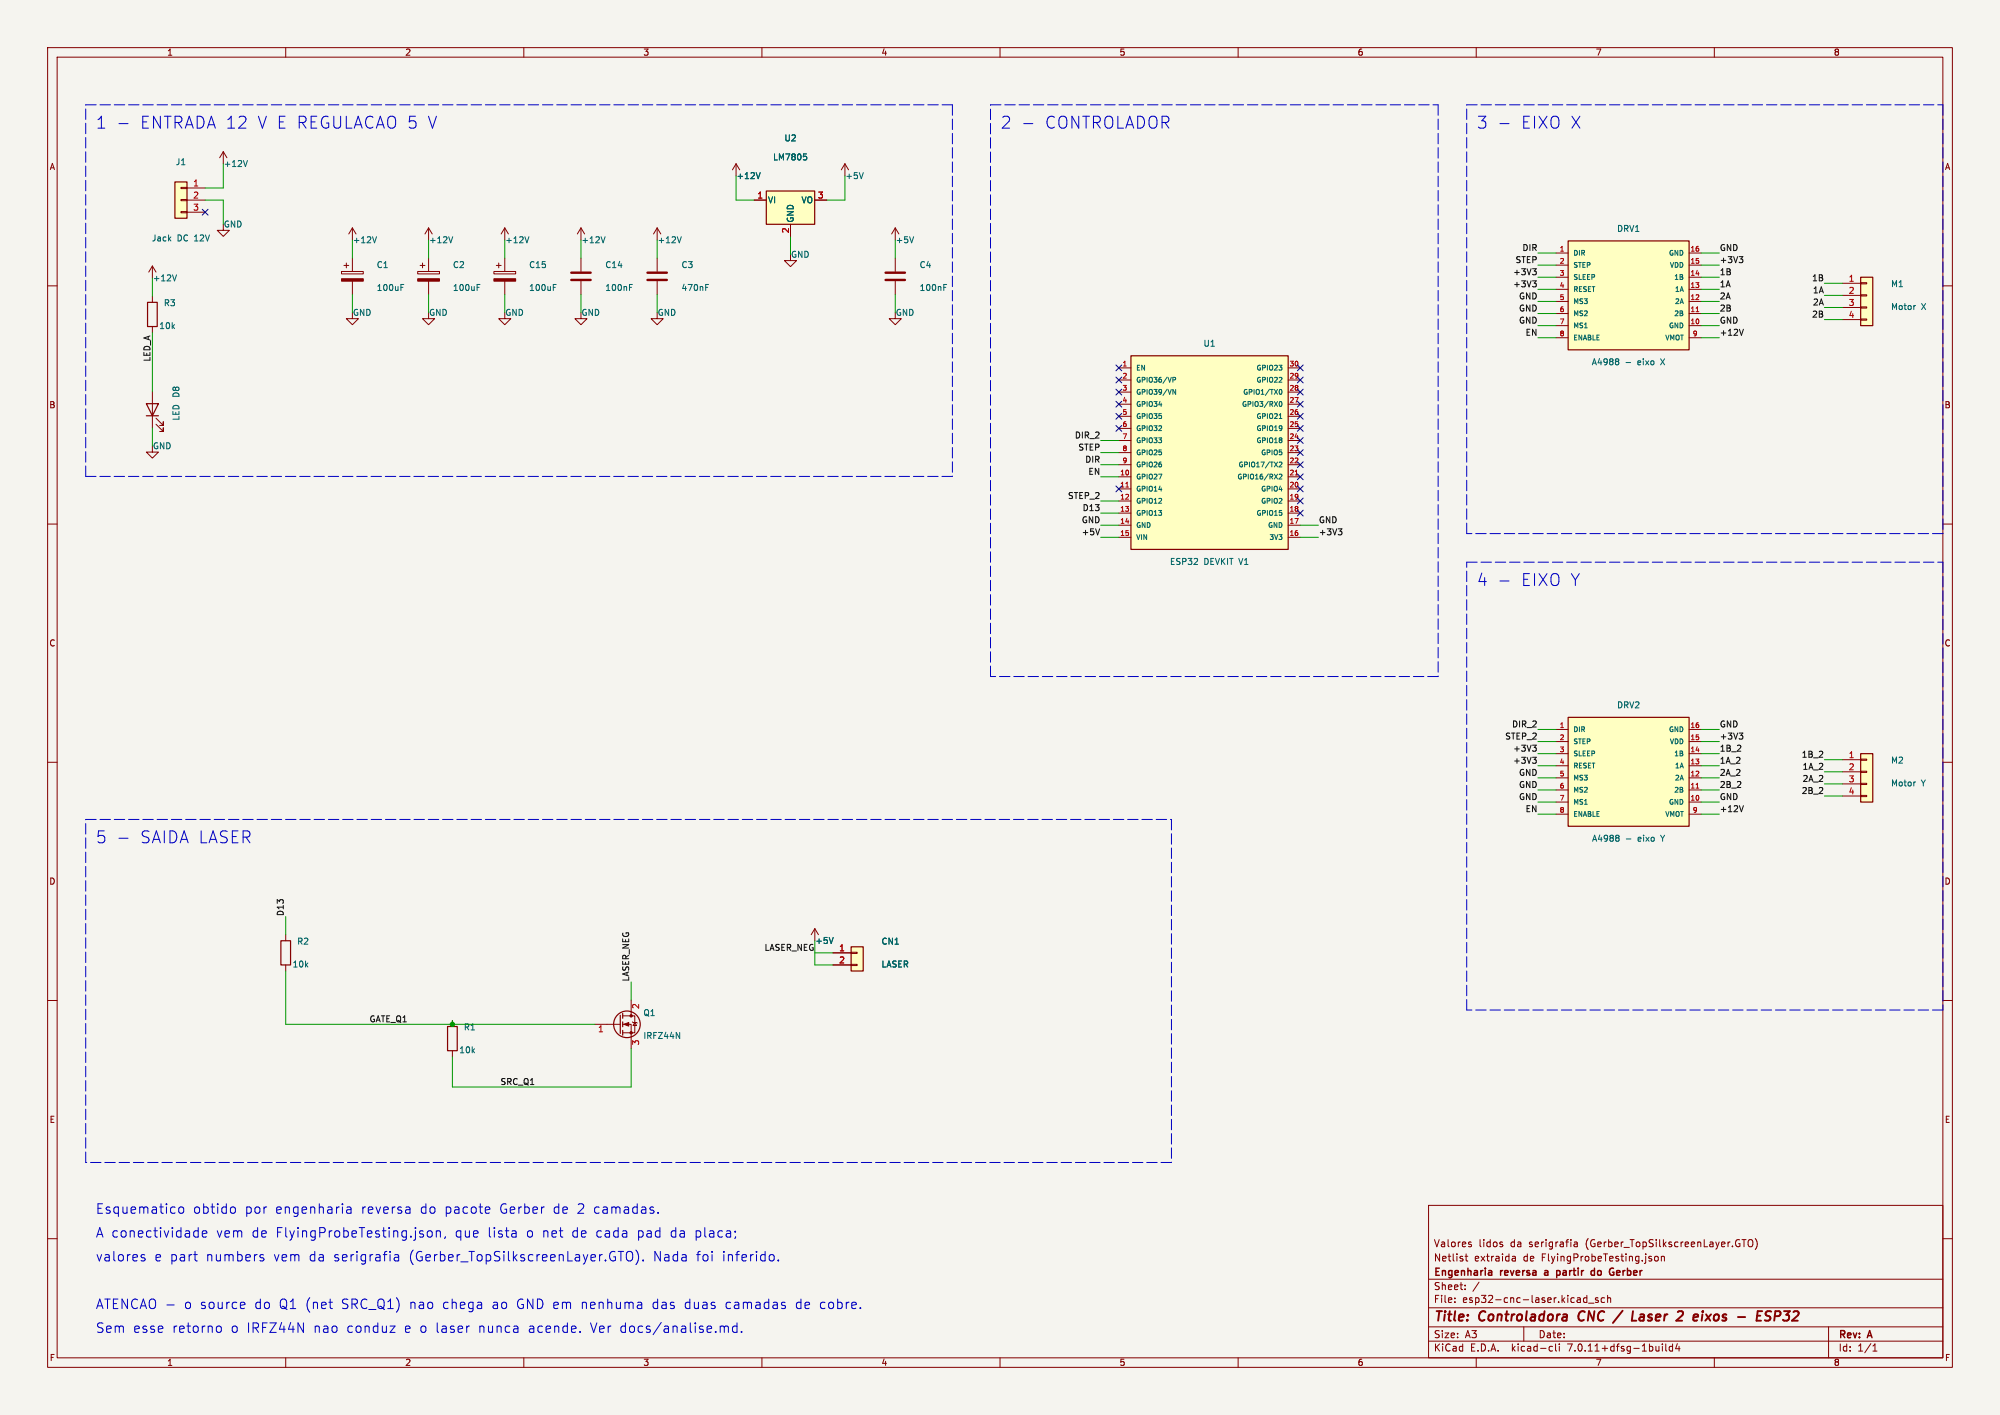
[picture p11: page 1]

ATENCAO - o source do Q1 (net SRC_Q1) nao chega ao GND em nenhuma das duas camadas de cobre.
Sem esse retorno o IRFZ44N nao conduz e o laser nunca acende. Ver docs/analise.md.

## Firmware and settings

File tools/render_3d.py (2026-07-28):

#!/usr/bin/env python3
"""Draw the board as an isometric 3D view.

What comes from the Gerber package and is therefore exact: the board outline,
the copper and silkscreen artwork, and the position and orientation of every
component (taken from the centroid of its own pads).

What does NOT come from the Gerber, because a Gerber has no such thing: the
height and the body shape of each part. Those are the usual dimensions for each
package, listed in BODIES below. So the layout is exact and the parts are
representative -- this is a drawing to look at, not a mechanical model.

    python3 tools/render_3d.py
"""
import json
import math
import re
from pathlib import Path

from gerbonara import GerberFile

ROOT = Path(__file__).resolve().parent.parent
GERBER = ROOT / "gerber"
OUT = ROOT / "docs"

MIL = 39.3701
THICK = 1.6                      # board thickness, mm
COS30, SIN30 = math.cos(math.radians(30)), math.sin(math.radians(30))
SCALE = 13                       # pixels per mm

PALETTE = {
    "board_top": "#1f6b3a",
    "board_side": "#14502a",
    "board_edge": "#0d3a1e",
    "silk": "#eef4f0",
    "pad": "#d9b24c",
    "trace": "#57c98a",
}

# w = size along the part's long axis, d = across it, h = height above the board
BODIES = {
    # geometry for these three lives in MODULES, below
    "U1":   dict(kind="module", label="ESP32"),
    "DRV1": dict(kind="module", label="A4988"),
    "DRV2": dict(kind="module", label="A4988"),
    # the jack body reaches out over the board edge, well behind its own pins
    "J1":   dict(kind="box", w=14.0, d=9.0, h=11.0, colour="#1b1b1b", label="12V",
                 offset=(-3.6, 0.0)),
    "M1":   dict(kind="box", w=10.2, d=5.8, h=8.5, colour="#e8e2d0", label="MOT X"),
    "M2":   dict(kind="box", w=10.2, d=5.8, h=8.5, colour="#e8e2d0", label="MOT Y"),
    "CN1":  dict(kind="box", w=6.4, d=6.0, h=8.5, colour="#e8e2d0", label="LASER"),
    "U2":   dict(kind="to220", w=10.2, d=4.6, h=16.0, colour="#23272b", label="7805"),
    "Q1":   dict(kind="to220", w=10.2, d=4.6, h=16.0, colour="#23272b", label="IRFZ44N"),
    "C1":   dict(kind="cyl", dia=6.3, h=11.0, colour="#2b3a8c"),
    "C2":   dict(kind="cyl", dia=6.3, h=11.0, colour="#2b3a8c"),
    "C15":  dict(kind="cyl", dia=6.3, h=11.0, colour="#2b3a8c"),
    "C3":   dict(kind="box", w=7.0, d=3.2, h=8.0, colour="#204a86"),
    "C4":   dict(kind="box", w=5.0, d=3.0, h=6.5, colour="#204a86"),
    "C14":  dict(kind="box", w=5.0, d=3.0, h=6.5, colour="#204a86"),
    "R1":   dict(kind="axial", dia=2.3, body=6.5, colour="#c8a06a"),
    "R2":   dict(kind="axial", dia=2.3, body=6.5, colour="#c8a06a"),
    "R3":   dict(kind="axial", dia=2.3, body=6.5, colour="#c8a06a"),
    "D8":   dict(kind="cyl", dia=5.0, h=8.6, colour="#cc2222"),
}

# The three plug-in modules are described as parts in their own right: their own
# board, their own pin headers, and the bits sitting on top of them. Sizes marked
# "medido" were read off the outline this board carries in its silkscreen; the
# rest are the published dimensions of the module.
MODULES = {
    "U1": dict(
        outline=(51.50, 27.94),        # medido na serigrafia da placa-mae
        centre=(37.14, 39.62),         # medido -- nao coincide com o centro dos pinos
        pcb="#1c1c22", stand=8.5, pcb_h=1.6, rows=(1, 15),
        features=[
            dict(dx=-11.0, dy=0.0, w=25.5, d=18.0, h=3.1, colour="#c2c6cc",
                 label="ESP32-WROOM-32"),
            dict(dx=23.0, dy=0.0, w=6.0, d=8.0, h=3.0, colour="#adb2b8", label="USB"),
            dict(dx=15.5, dy=-9.5, w=4.5, d=3.5, h=1.9, colour="#141414", label="EN"),
            dict(dx=15.5, dy=9.5, w=4.5, d=3.5, h=1.9, colour="#141414", label="BOOT"),
        ]),
    "DRV1": dict(
        outline=(20.32, 15.24), centre=None,
        pcb="#8b1e2d", stand=8.5, pcb_h=1.6, rows=(1, 8),
        features=[
            dict(dx=0.0, dy=1.0, w=5.2, d=5.2, h=1.0, colour="#26262a", label="A4988"),
            dict(dx=-6.6, dy=-3.6, w=4.2, d=4.2, h=2.2, colour="#1f4fa8", label="Vref"),
            dict(dx=6.4, dy=-3.8, w=3.2, d=1.8, h=1.2, colour="#3a3a3a", label=""),
        ]),
}
MODULES["DRV2"] = dict(MODULES["DRV1"])

# silkscreen name + pad count -> reference, matching the schematic
REFS = {
    ("ESP32 DEVKIT V1", 30): "U1", ("EJE X", 16): "DRV1", ("XA2_EJE_Y", 16): "DRV2",
    ("EJE X", 4): "M1", ("EJE Y", 4): "M2", ("DC_CARGADOR", 3): "J1",
    ("CN1", 2): "CN1", ("U2", 3): "U2", ("Q1", 3): "Q1",
    ("C1", 2): "C1", ("C2", 2): "C2", ("C15", 2): "C15", ("C3", 2): "C3",
    ("C4", 2): "C4", ("C14", 2): "C14", ("R1", 2): "R1", ("R2", 2): "R2",
    ("R3", 2): "R3", ("D8", 2): "D8",
}


# ---------------------------------------------------------------- geometry
VIEW = {"angle": 0.0, "ox": 35.0, "oy": 27.0}


def spin(x, y):
    """Turn the board under a fixed camera, so several views can be compared."""
    a = math.radians(VIEW["angle"])
    dx, dy = x - VIEW["ox"], y - VIEW["oy"]
    return (VIEW["ox"] + dx * math.cos(a) - dy * math.sin(a),
            VIEW["oy"] + dx * math.sin(a) + dy * math.cos(a))


def project(x, y, z):
    """Isometric view from above. sx uses (y - x) so the screen basis stays
    right-handed -- with (x - y) the board comes out mirrored."""
    xr, yr = spin(x, y)
    return ((yr - xr) * COS30, (xr + yr) * SIN30 - z)


def depth_of(x, y):
    xr, yr = spin(x, y)
    return xr + yr


def outline():
    segs = [((o.x1, o.y1), (o.x2, o.y2))
            for o in GerberFile.open(GERBER / "Gerber_BoardOutlineLayer.GKO").objects]
    pts, cur = [segs[0][0]], segs[0][1]
    used = {0}
    while len(used) < len(segs):
        for i, (a, b) in enumerate(segs):
            if i in used:
                continue
            if math.dist(a, cur) < 1e-6:
                pts.append(cur); cur = b; used.add(i); break
            if math.dist(b, cur) < 1e-6:
                pts.append(cur); cur = a; used.add(i); break
        else:
            break
    pts.append(cur)
    return pts


def pads_by_part():
    data = json.loads((GERBER / "FlyingProbeTesting.json").read_text())
    idx = {n: i for i, n in enumerate(data["pins"]["fields"])}
    groups = {}
    for row in data["pins"]["rows"]:
        if row[idx["LAYER"]] != "T":
            continue
        name = row[idx["PIN_NAME"]]
        if name.startswith("PAD"):
            continue
        ref, pin = name.rsplit("_", 1)
        xy = (row[idx["PIN_X"]] / MIL, row[idx["PIN_Y"]] / MIL)
        # two different parts are silkscreened "EJE X": the driver sits well to
        # the right of the motor header, so the x coordinate separates them
        key = (ref, "drv" if ref == "EJE X" and xy[0] > 12 else "a")
        groups.setdefault(key, {})[pin] = xy
    out = {}
    for (ref, _), pins in groups.items():
        out.setdefault((ref, len(pins)), pins)
    return out


def placement(pins, body=None):
    xs = [p[0] for p in pins.values()]
    ys = [p[1] for p in pins.values()]
    cx, cy = (min(xs) + max(xs)) / 2, (min(ys) + max(ys)) / 2
    horizontal = (max(xs) - min(xs)) >= (max(ys) - min(ys))
    ox, oy = (body or {}).get("offset", (0.0, 0.0))
    if not horizontal:
        ox, oy = oy, ox
    return cx + ox, cy + oy, horizontal


# ---------------------------------------------------------------- shading
def shade(hex_colour, factor):
    r, g, b = (int(hex_colour[i:i + 2], 16) for i in (1, 3, 5))
    f = lambda v: max(0, min(255, int(v * factor)))
    return f"#{f(r):02x}{f(g):02x}{f(b):02x}"


class Scene:
    def __init__(self):
        self.faces = []

    def add(self, pts3, colour, depth, stroke=None, width=0.05):
        flat = " ".join(f"{px:.3f},{py:.3f}" for px, py in (project(*p) for p in pts3))
        self.faces.append((depth, flat, colour, stroke, width))

    def box(self, cx, cy, z0, w, d, h, colour):
        x0, x1 = cx - w / 2, cx + w / 2
        y0, y1 = cy - d / 2, cy + d / 2
        z1 = z0 + h
        depth = depth_of(cx, cy)
        self.add([(x1, y0, z0), (x1, y1, z0), (x1, y1, z1), (x1, y0, z1)],
                 shade(colour, 0.80), depth - 0.2)
        self.add([(x0, y1, z0), (x1, y1, z0), (x1, y1, z1), (x0, y1, z1)],
                 shade(colour, 0.62), depth - 0.1)
        self.add([(x0, y0, z1), (x1, y0, z1), (x1, y1, z1), (x0, y1, z1)],
                 shade(colour, 1.0), depth)

    def cylinder(self, cx, cy, z0, dia, h, colour, sides=18):
        r, z1 = dia / 2, z0 + h
        ring = [(cx + r * math.cos(2 * math.pi * i / sides),
                 cy + r * math.sin(2 * math.pi * i / sides)) for i in range(sides)]
        depth = depth_of(cx, cy)
        for i in range(sides):
            ax, ay = ring[i]
            bx, by = ring[(i + 1) % sides]
            mx, my = (ax + bx) / 2, (ay + by) / 2
            rel = depth_of(mx, my) - depth
            if rel < 0:                      # back half is hidden by the front half
                continue
            lit = 0.55 + 0.35 * (rel + r) / (2 * r)
            self.add([(ax, ay, z0), (bx, by, z0), (bx, by, z1), (ax, ay, z1)],
                     shade(colour, lit), depth - 0.3 + rel / 100)
        self.add([(x, y, z1) for x, y in ring], shade(colour, 1.05), depth)

    def svg_faces(self):
        for depth, pts, fill, stroke, width in sorted(self.faces, key=lambda f: f[0]):
            extra = f' stroke="{stroke}" stroke-width="{width}"' if stroke else ""
            yield f'<polygon points="{pts}" fill="{fill}"{extra}/>'


# ---------------------------------------------------------------- artwork
def art_bounds():
    """One box covering every layer, so all of them share a flip axis."""
    boxes = [GerberFile.open(GERBER / f).bounding_box() for f in
             ("Gerber_TopLayer.GTL", "Gerber_TopSilkscreenLayer.GTO",
              "Gerber_BoardOutlineLayer.GKO")]
    return ((min(b[0][0] for b in boxes) - 1, min(b[0][1] for b in boxes) - 1),
            (max(b[1][0] for b in boxes) + 1, max(b[1][1] for b in boxes) + 1))


def layer_group(filename, colour, z, box):
    g = GerberFile.open(GERBER / filename)
    if not g.objects:
        return ""
    flip = box[0][1] + box[1][1]
    svg = str(g.to_svg(fg=colour, bg="none", force_bounds=box))
    m = re.search(r"(<g transform=.*</g>)\s*</svg>\s*$", svg, re.S)
    if not m:
        return ""
    # content arrives in SVG coords (u, v) = (x, flip - y). Sample the very same
    # projection the solid geometry uses at three points and read the affine off
    # it -- that way the artwork can never drift away from the parts.
    def at(u, v):
        return project(u, flip - v, z)

    ox, oy = at(0, 0)
    ax, ay = at(1, 0)
    bx, by = at(0, 1)
    a, b = ax - ox, ay - oy
    c, d = bx - ox, by - oy
    return (f'<g transform="matrix({a:.6f} {b:.6f} {c:.6f} {d:.6f} {ox:.6f} {oy:.6f})">'
            f"{m.group(1)}</g>")


def render_view(angle, label_all=False, only=None):
    poly = outline()
    parts = pads_by_part()
    xs_p = [q[0] for q in poly]; ys_p = [q[1] for q in poly]
    VIEW["angle"] = angle
    VIEW["ox"] = (min(xs_p) + max(xs_p)) / 2
    VIEW["oy"] = (min(ys_p) + max(ys_p)) / 2

    scene = Scene()
    top = THICK
    cx0 = sum(xs_p) / len(poly)
    cy0 = sum(ys_p) / len(poly)
    for i in range(len(poly) - 1):
        (ax, ay), (bx, by) = poly[i], poly[i + 1]
        mx, my = (ax + bx) / 2, (ay + by) / 2
        if depth_of(mx, my) < depth_of(cx0, cy0):   # far wall, hidden by the slab
            continue
        scene.add([(ax, ay, 0), (bx, by, 0), (bx, by, top), (ax, ay, top)],
                  PALETTE["board_side"], -1000 + depth_of(mx, my))
    scene.add([(x, y, top) for x, y in poly], PALETTE["board_top"], -999,
              stroke=PALETTE["board_edge"], width=0.08)

    board_faces = list(scene.svg_faces())
    abox = art_bounds()
    art = [
        layer_group("Gerber_TopLayer.GTL", PALETTE["trace"], top, abox),
        layer_group("Gerber_TopSilkscreenLayer.GTO", PALETTE["silk"], top, abox),
    ]
    scene.faces.clear()

    labels = []
    for key, ref in REFS.items():
        pins = parts.get(key)
        if not pins:
            print("sem pads:", key)
            continue
        if only is not None and ref != only:
            continue
        body = BODIES[ref]
        cx, cy, horiz = placement(pins, body)
        kind = body["kind"]
        crown = top
        if kind == "cyl":
            scene.cylinder(cx, cy, top, body["dia"], body["h"], body["colour"])
            crown = top + body["h"]
        elif kind == "axial":
            w, d = (body["body"], body["dia"]) if horiz else (body["dia"], body["body"])
            scene.box(cx, cy, top, w, d, body["dia"], body["colour"])
            crown = top + body["dia"]
        elif kind == "to220":
            w, d = (body["w"], body["d"]) if horiz else (body["d"], body["w"])
            scene.box(cx, cy, top + 2.5, w, d, body["h"], body["colour"])
            crown = top + 2.5 + body["h"]
        elif kind == "module":
            mod = MODULES[ref]
            if mod["centre"]:
                cx, cy = mod["centre"]
            ow, od = mod["outline"]
            if not horiz:
                ow, od = od, ow
            for px, py in pins.values():
                scene.box(px, py, top, 0.7, 0.7, mod["stand"], "#b8b8b8")
            zpcb = top + mod["stand"]
            scene.box(cx, cy, zpcb, ow, od, mod["pcb_h"], mod["pcb"])
            for ft in mod["features"]:
                fx, fy = (ft["dx"], ft["dy"]) if horiz else (-ft["dy"], ft["dx"])
                fw, fd = (ft["w"], ft["d"]) if horiz else (ft["d"], ft["w"])
                scene.box(cx + fx, cy + fy, zpcb + mod["pcb_h"], fw, fd, ft["h"],
                          ft["colour"])
            crown = zpcb + mod["pcb_h"] + max(f["h"] for f in mod["features"])
        else:
            w, d = (body["w"], body["d"]) if horiz else (body["d"], body["w"])
            scene.box(cx, cy, top, w, d, body["h"], body["colour"])
            crown = top + body["h"]
        caption = ref if label_all else body.get("label")
        if caption:
            labels.append((cx, cy, crown, caption))

    part_faces = list(scene.svg_faces())
    text = []
    for cx, cy, cz, caption in labels:
        px, py = project(cx, cy, cz)
        # paint-order is not honoured by every renderer, so the halo is a
        # separate stroke-only copy drawn underneath the filled text
        common = (f'x="{px:.2f}" y="{py - 1.6:.2f}" font-size="2.4" '
                  f'font-family="DejaVu Sans" font-weight="bold" text-anchor="middle"')
        text.append(f'<text {common} fill="none" stroke="#ffffff" '
                    f'stroke-width="0.9" stroke-linejoin="round">{caption}</text>')
        text.append(f'<text {common} fill="#1a2730">{caption}</text>')

    xs, ys = [], []
    for x, y in poly:
        for z in (0, 26):
            px, py = project(x, y, z)
            xs.append(px); ys.append(py)
    pad = 2.5
    x0, x1 = min(xs) - pad, max(xs) + pad
    y0, y1 = min(ys) - pad, max(ys) + pad
    w, h = x1 - x0, y1 - y0
    return (f'<svg xmlns="http://www.w3.org/2000/svg" viewBox="{x0:.2f} {y0:.2f} '
            f'{w:.2f} {h:.2f}" width="{w * SCALE:.0f}" height="{h * SCALE:.0f}">'
            f'<rect x="{x0:.2f}" y="{y0:.2f}" width="{w:.2f}" height="{h:.2f}" '
            f'fill="#f4f6f8"/>' + "".join(board_faces) + "".join(art)
            + "".join(part_faces) + "".join(text) + "</svg>")


def render_plan(geom=None, only=None, width_px=22):
    """Top-down check: part bodies drawn translucent over the silkscreen.
    A body that does not land on its own silkscreen outline is misplaced.
    `only` restricts the drawing to a single reference; use "" for the bare board."""
    geom = geom if geom is not None else parts_geometry()
    box = art_bounds()
    (bx0, by0), (bx1, by1) = box
    flip = by0 + by1
    w, h = bx1 - bx0, by1 - by0

    def to_svg(x, y):
        return x, flip - y

    out = [f'<svg xmlns="http://www.w3.org/2000/svg" viewBox="{bx0:.2f} {by0:.2f} '
           f'{w:.2f} {h:.2f}" width="{w * width_px:.0f}" height="{h * width_px:.0f}">'
           f'<rect x="{bx0:.2f}" y="{by0:.2f}" width="{w:.2f}" height="{h:.2f}" fill="white"/>']

    for fn, colour in (("Gerber_TopLayer.GTL", "#c9d6e8"),
                       ("Gerber_TopSilkscreenLayer.GTO", "#333333")):
        g = GerberFile.open(GERBER / fn)
        svg = str(g.to_svg(fg=colour, bg="none", force_bounds=box))
        m = re.search(r"(<g transform=.*</g>)\s*</svg>\s*$", svg, re.S)
        if m:
            out.append(m.group(1))

    for part in geom:
        if only is not None and part["ref"] != only:
            continue
        ref, cx, cy, horiz = part["ref"], part["cx"], part["cy"], part["horiz"]
        body = BODIES[ref]
        if body["kind"] == "module":
            mod = MODULES[ref]
            if mod["centre"]:
                cx, cy = mod["centre"]
            bw, bd = mod["outline"]
            if not horiz:
                bw, bd = bd, bw
            px, py = to_svg(cx - bw / 2, cy + bd / 2)
            out.append(f'<rect x="{px:.2f}" y="{py:.2f}" width="{bw:.2f}" '
                       f'height="{bd:.2f}" fill="#e0362c" fill-opacity="0.30" '
                       f'stroke="#b0231a" stroke-width="0.18"/>')
        elif body["kind"] == "cyl":
            px, py = to_svg(cx, cy)
            out.append(f'<circle cx="{px:.2f}" cy="{py:.2f}" r="{body["dia"] / 2:.2f}" '
                       f'fill="#e0362c" fill-opacity="0.30" stroke="#b0231a" '
                       f'stroke-width="0.18"/>')
        else:
            if body["kind"] == "axial":
                bw, bd = body["body"], body["dia"]
            else:
                bw, bd = body["w"], body["d"]
            if not horiz:
                bw, bd = bd, bw
            px, py = to_svg(cx - bw / 2, cy + bd / 2)
            out.append(f'<rect x="{px:.2f}" y="{py:.2f}" width="{bw:.2f}" '
                       f'height="{bd:.2f}" fill="#e0362c" fill-opacity="0.30" '
                       f'stroke="#b0231a" stroke-width="0.18"/>')
        lx, ly = to_svg(cx, cy)
        for fill, stroke, sw in (("none", "#ffffff", 0.8), ("#8a1008", "none", 0)):
            extra = f' stroke="{stroke}" stroke-width="{sw}"' if stroke != "none" else ""
            out.append(f'<text x="{lx:.2f}" y="{ly + 0.7:.2f}" font-size="2" '
                       f'font-family="DejaVu Sans" font-weight="bold" '
                       f'text-anchor="middle" fill="{fill}"{extra}>{ref}</text>')
    out.append("</svg>")
    return "".join(out)


# ------------------------------------------------- one part at a time
def parts_geometry():
    """Every part reduced to plain boxes and cylinders, so the isometric, plan
    and elevation views all draw from one single description."""
    parts = pads_by_part()
    out = []
    for key, ref in REFS.items():
        pins = parts.get(key)
        if not pins:
            continue
        body = BODIES[ref]
        cx, cy, horiz = placement(pins, body)
        kind = body["kind"]
        solids = []
        if kind == "cyl":
            solids.append(dict(shape="cyl", cx=cx, cy=cy, z=THICK,
                               dia=body["dia"], h=body["h"], colour=body["colour"]))
        elif kind == "axial":
            w, d = (body["body"], body["dia"]) if horiz else (body["dia"], body["body"])
            solids.append(dict(shape="box", cx=cx, cy=cy, z=THICK, w=w, d=d,
                               h=body["dia"], colour=body["colour"]))
        elif kind == "to220":
            w, d = (body["w"], body["d"]) if horiz else (body["d"], body["w"])
            solids.append(dict(shape="box", cx=cx, cy=cy, z=THICK + 2.5, w=w, d=d,
                               h=body["h"], colour=body["colour"]))
        elif kind == "module":
            mod = MODULES[ref]
            if mod["centre"]:
                cx, cy = mod["centre"]
            ow, od = mod["outline"]
            if not horiz:
                ow, od = od, ow
            for px, py in pins.values():
                solids.append(dict(shape="box", cx=px, cy=py, z=THICK, w=0.7, d=0.7,
                                   h=mod["stand"], colour="#b8b8b8"))
            zpcb = THICK + mod["stand"]
            solids.append(dict(shape="box", cx=cx, cy=cy, z=zpcb,
                               w=ow, d=od, h=mod["pcb_h"], colour=mod["pcb"]))
            for ft in mod["features"]:
                fx, fy = (ft["dx"], ft["dy"]) if horiz else (-ft["dy"], ft["dx"])
                fw, fd = (ft["w"], ft["d"]) if horiz else (ft["d"], ft["w"])
                solids.append(dict(shape="box", cx=cx + fx, cy=cy + fy,
                                   z=zpcb + mod["pcb_h"], w=fw, d=fd, h=ft["h"],
                                   colour=ft["colour"]))
        else:
            w, d = (body["w"], body["d"]) if horiz else (body["d"], body["w"])
            solids.append(dict(shape="box", cx=cx, cy=cy, z=THICK, w=w, d=d,
                               h=body["h"], colour=body["colour"]))
        top_z = max(sd["z"] + sd.get("h", 0) for sd in solids)
        out.append(dict(ref=ref, cx=cx, cy=cy, horiz=horiz, pins=pins,
                        solids=solids, top=top_z))
    return out


# camera axes for the four straight-on side views
ELEVATIONS = {
    "frente": dict(title="VISTA FRONTAL  (olhando de Y-)",
                   sx=lambda x, y: x, depth=lambda x, y: -y),
    "tras":   dict(title="VISTA TRASEIRA  (olhando de Y+)",
                   sx=lambda x, y: -x, depth=lambda x, y: y),
    "esq":    dict(title="VISTA ESQUERDA  (olhando de X-)",
                   sx=lambda x, y: y, depth=lambda x, y: -x),
    "dir":    dict(title="VISTA DIREITA  (olhando de X+)",
                   sx=lambda x, y: -y, depth=lambda x, y: x),
}
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

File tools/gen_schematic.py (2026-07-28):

#!/usr/bin/env python3
"""Generate a KiCad schematic from the board's flying-probe netlist.

The netlist (component, pin, net for every pad) is read straight out of
FlyingProbeTesting.json that ships with the Gerber package, so the connectivity
in the schematic is the board's real connectivity -- nothing is inferred.
Component values and part numbers come from the top silkscreen layer.
"""
import json
import sys
import uuid
from math import cos, radians, sin
from pathlib import Path

sys.path.insert(0, str(Path(__file__).parent))
import ksym

ROOT = Path(__file__).resolve().parent.parent
GERBER = ROOT / "gerber"
OUT = ROOT / "hardware" / "esp32-cnc-laser.kicad_sch"
NS = uuid.UUID("6f1d4e8a-2b7c-4a19-9d3e-5c8a0b1f7e42")


def uid(key):
    return str(uuid.uuid5(NS, key))


# --------------------------------------------------------------------------
# Board data: how each silkscreen part maps to a schematic symbol.
# key = (silkscreen name, pin count) because two parts share the name "EJE X".
# --------------------------------------------------------------------------
PARTS = {
    ("DC_CARGADOR", 3): dict(ref="J1", lib="Connector_Generic:Conn_01x03",
                             value="Jack DC 12V", at=(38, 42), mirror="y"),
    ("R3", 2):          dict(ref="R3", lib="Device:R", value="10k", at=(32, 66), angle=180),
    ("D8", 2):          dict(ref="D8", lib="Device:LED", value="LED", at=(32, 86), angle=90,
                         pinmap={"1": "2", "2": "1"}),  # pad1=anodo na placa
    ("C1", 2):          dict(ref="C1", lib="Device:C_Polarized", value="100uF", at=(74, 58)),
    ("C2", 2):          dict(ref="C2", lib="Device:C_Polarized", value="100uF", at=(90, 58)),
    ("C15", 2):         dict(ref="C15", lib="Device:C_Polarized", value="100uF", at=(106, 58)),
    ("C14", 2):         dict(ref="C14", lib="Device:C", value="100nF", at=(122, 58)),
    ("C3", 2):          dict(ref="C3", lib="Device:C", value="470nF", at=(138, 58)),
    ("U2", 3):          dict(ref="U2", lib="Regulator_Linear:LM7805_TO220",
                             value="LM7805", at=(166, 42)),
    ("C4", 2):          dict(ref="C4", lib="Device:C", value="100nF", at=(188, 58)),
    ("ESP32 DEVKIT V1", 30): dict(ref="U1", lib="Module:ESP32_DEVKIT_V1",
                                  value="ESP32 DEVKIT V1", at=(254, 95)),
    ("EJE X", 16):      dict(ref="DRV1", lib="Module:A4988", value="A4988 - eixo X", at=(342, 62)),
    ("EJE X", 4):       dict(ref="M1", lib="Connector_Generic:Conn_01x04",
                             value="Motor X", at=(392, 62)),
    ("XA2_EJE_Y", 16):  dict(ref="DRV2", lib="Module:A4988", value="A4988 - eixo Y", at=(342, 162)),
    ("EJE Y", 4):       dict(ref="M2", lib="Connector_Generic:Conn_01x04",
                             value="Motor Y", at=(392, 162)),
    ("R2", 2):          dict(ref="R2", lib="Device:R", value="10k", at=(60, 200), angle=180),
    ("R1", 2):          dict(ref="R1", lib="Device:R", value="10k", at=(95, 218), angle=180),
    ("Q1", 3):          dict(ref="Q1", lib="Device:Q_NMOS_GDS", value="IRFZ44N", at=(130, 215)),
    ("CN1", 2):         dict(ref="CN1", lib="Connector_Generic:Conn_01x02",
                             value="LASER", at=(180, 200)),
}

# Symbols big enough that Reference/Value must sit outside the body.
BIG = {
    "Module:ESP32_DEVKIT_V1": (-22.9, 22.9),
    "Module:A4988": (-14.0, 14.0),
    "Regulator_Linear:LM7805_TO220": (-13.0, -9.0),
    "Connector_Generic:Conn_01x03": (-8.0, 8.0),   # J1 is mirrored;
                                                   # KiCad flips field justify with it
}
MODULES = {"Module:ESP32_DEVKIT_V1", "Module:A4988"}

# Nets carried by a power symbol rather than a text label.
POWER = {"+12V": "power:+12V", "+5V": "power:+5V",
         "+3V3": "power:+3V3", "GND": "power:GND"}

# The board leaves three nets unnamed ($1N....); give them readable names.
RENAME = {"$1N1790": "GATE_Q1", "$1N1796": "SRC_Q1", "$1N2332": "LED_A",
          "12V": "+12V", "5V": "+5V", "3.3V": "+3V3"}

PIN_NAMES = {
    "Module:ESP32_DEVKIT_V1": [
        "EN", "GPIO36/VP", "GPIO39/VN", "GPIO34", "GPIO35", "GPIO32", "GPIO33", "GPIO25",
        "GPIO26", "GPIO27", "GPIO14", "GPIO12", "GPIO13", "GND", "VIN",
        "3V3", "GND", "GPIO15", "GPIO2", "GPIO4", "GPIO16/RX2", "GPIO17/TX2", "GPIO5",
        "GPIO18", "GPIO19", "GPIO21", "GPIO3/RX0", "GPIO1/TX0", "GPIO22", "GPIO23",
    ],
    "Module:A4988": [
        "DIR", "STEP", "SLEEP", "RESET", "MS3", "MS2", "MS1", "ENABLE",
        "VMOT", "GND", "2B", "2A", "1A", "1B", "VDD", "GND",
    ],
}


# --------------------------------------------------------------------------
# Symbol construction
# --------------------------------------------------------------------------
def rect_symbol(name, pin_names, half_w, pitch=2.54, stub=2.54):
    """Build a DIP-style rectangular symbol: pins 1..n/2 down the left side,
    the rest back up the right side (counter-clockwise, like a real package)."""
    n = len(pin_names)
    per_side = n // 2
    span = (per_side - 1) * pitch
    half_h = span / 2 + pitch
    body_w = half_w
    lines = [
        f'(symbol "{name}" (pin_names (offset 1.016)) (in_bom yes) (on_board yes)',
        f'  (property "Reference" "U" (at 0 {half_h + 2.54:.2f} 0) (effects (font (size 1.27 1.27))))',
        f'  (property "Value" "{name.split(":")[-1]}" (at 0 {-half_h - 2.54:.2f} 0) (effects (font (size 1.27 1.27))))',
        f'  (property "Footprint" "" (at 0 0 0) (effects (font (size 1.27 1.27)) hide))',
        f'  (property "Datasheet" "" (at 0 0 0) (effects (font (size 1.27 1.27)) hide))',
        f'  (symbol "{name.split(":")[-1]}_0_1"',
        f'    (rectangle (start {-body_w:.2f} {half_h:.2f}) (end {body_w:.2f} {-half_h:.2f})',
        f'      (stroke (width 0.254) (type default)) (fill (type background))))',
        f'  (symbol "{name.split(":")[-1]}_1_1"',
    ]
    pins = {}
    for i, pname in enumerate(pin_names, start=1):
        if i <= per_side:
            y = span / 2 - (i - 1) * pitch
            x = -body_w - stub
            angle = 0
        else:
            j = i - per_side - 1
            y = -span / 2 + j * pitch
            x = body_w + stub
            angle = 180
        etype = "power_in" if pname in ("GND", "VIN", "3V3", "VMOT", "VDD") else "passive"
        lines.append(
            f'    (pin {etype} line (at {x:.2f} {y:.2f} {angle}) (length {stub:.2f})'
            f' (name "{pname}" (effects (font (size 1.016 1.016))))'
            f' (number "{i}" (effects (font (size 1.016 1.016)))))'
        )
        pins[str(i)] = (x, y)
    lines.append("  )")
    lines.append(")")
    return "\n".join("    " + ln for ln in lines), pins


def stock_symbol(lib_id):
    lib, name = lib_id.split(":")
    sym = ksym.resolve(lib, name)
    sym = [c for c in sym]
    sym[1] = f'"{lib_id}"'
    return "    " + ksym.dump(sym, 2), ksym.pins(sym)
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

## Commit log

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2026-07-28 Reconstrói o esquemático da controladora CNC/laser a partir do Gerber
    Engenharia reversa da placa dupla face do pacote Gerber, gerando o
    esquemático elétrico em KiCad.
    A conectividade vem de FlyingProbeTesting.json, que traz o net de cada pad;
    valores e part numbers foram lidos da serigrafia renderizada a partir do
    Gerber. Nada de conectividade foi inferido.
    O esquemático é gerado por script (tools/gen_schematic.py) e conferido por
    duas verificações independentes:
    - verify_netlist.py compara a netlist exportada do .kicad_sch com a da
    placa: 22 de 22 nets idênticos.
    - check_copper.py rasteriza as duas camadas de cobre usando as aberturas do
    próprio Gerber, rotula as ilhas con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
    [Drill_PTH_Through.DRL, Drill_PTH_Through_Via.DRL, Gerber_BoardOutlineLayer.GKO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]
2026-07-28 Desenha o layout da placa a partir do Gerber
    Renderiza o pacote Gerber como desenho de layout: trilhas da face superior em
    azul-escuro, da inferior em azul-claro, pads em verde e serigrafia em cinza,
    com a borda da placa por cima.
    Cada camada é renderizada pelo mesmo bounding box forçado, então elas se
    sobrepõem alinhadas. Os limites cobrem todas as camadas, e não só a borda da
    placa, para que a serigrafia que passa da borda não seja cortada.
    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
2026-07-28 Desenha a placa em 3D isometrico, com prancha de vistas
    Monta a placa em tres dimensoes a partir do Gerber: a laje da placa vem do
    contorno, a arte de cobre e serigrafia e projetada sobre a face superior, e
    cada componente e posicionado pelo centro dos seus proprios pads.
    A prancha reune a vista de topo com os corpos desenhados translucidos sobre a
    serigrafia -- que e como se confere posicionamento -- mais o mesmo conjunto
    visto de quatro angulos, cada peca rotulada com a sua referencia.
    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
2026-07-28 Acrescenta vistas laterais reais e conferencia peca por peca
    As quatro vistas laterais sao ortograficas, com a camera na altura da placa e
    nao acima dela, entao a altura de cada peca sai verdadeira -- coisa que uma
    vista isometrica nao da.
    --steps grava uma pagina por peca em docs/posicionamento/, comecando pela placa
    nua: cada pagina traz a placa sozinha mais uma unica peca, de topo sobre a
    serigrafia, em perspectiva e nas quatro laterais. As demais peças ficam a 12 %
    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
2026-07-28 Acrescenta a vista de topo com as pecas solidas
    Ate agora a unica vista de cima era o raio X, com os corpos translucidos sobre a
    serigrafia. Essa serve para conferir se a peca cai em cima do proprio contorno,
    mas nao mostra como a placa montada realmente se ve.
    A vista nova desenha as pecas opacas, empilhadas por altura, entao o que esta
    por cima tapa o que esta por baixo -- e o caso do driver A4988, que esconde o
    eletrolitico que fica debaixo dele.
    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
2026-07-28 Modela os modulos como pecas proprias, medidas na serigrafia
    Ate agora os tres modulos eram caixas com dimensao chutada por mim. Agora cada
    um e uma peca em si: contorno proprio, barra de pinos propria e as pecas que
    ficam em cima dele.
    O contorno do ESP32 foi medido no desenho que a placa-mae carrega na serigrafia
    para ele: 51,50 x 27,94 mm, que e a medida real do DevKit V1, contra os 48 x
    25,4 que eu vinha usando. O centro desse contorno fica 2,5 mm deslocado do
    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
2026-07-28 Reposiciona os modulos nas paginas e avisa da folga onde ela importa
    Regera as paginas de posicionamento, a prancha e os quatro angulos com os
    modulos ja modelados pelas medidas reais -- ate agora essas saidas ainda
    carregavam as caixas antigas de dimensao chutada.
    Alem disso, as paginas de C1, C2, DRV1 e DRV2 passam a trazer o aviso da falta
    de folga no proprio cabecalho, com os numeros e a ressalva de que as alturas sao
    valores tipicos. O relatorio no terminal continua existindo, mas quem abre a
    pagina da peca ve o problema sem precisar rodar nada.
    Claude-Session: https://claude.ai/code/session_01EdajzGDEe7KTFzmERVeduR
    [render_3d.py]
2026-07-28 Publica um visualizador 3D interativo no GitHub Pages
    Pagina estatica na raiz do repositorio, que o Pages serve a partir da main.
    A placa aparece em 3D de verdade, com orbita e zoom; o menu lateral liga e
    desliga cada peca ou um grupo inteiro, e o botao Placa esconde a propria placa
    para dar de ver o que fica por baixo dos modulos. Duplo clique em qualquer
    componente abre para que ele serve, com a lista de pino para net daquele
    componente. As pecas do conflito de folga vem marcadas no menu.
    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
2026-07-28 Desliga o Jekyll no GitHub Pages
    Sem .nojekyll o Pages passa o repositorio pelo Jekyll, que gera um index.html a
    partir do README quando nao encontra um proprio -- era o que servia a pagina
    antiga. Com o arquivo presente os arquivos vao para o ar como estao, o build
    fica mais rapido e o Jekyll nao tem chance de engasgar em nada do repositorio.
    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
2026-07-28 Acompanha o novo nome do repositorio e fixa o contexto em CLAUDE.md
    O repositorio passou de brigsd/Achievements para brigsd/Eletrifica. O Pages nao
    redireciona repositorio renomeado: a URL antiga responde 404, entao os links do
    README e do visualizador apontavam para o vazio. Todos foram corrigidos.
    Acrescenta CLAUDE.md, que e lido do disco a cada sessao. Ele registra o nome
    atual, avisa que o nome antigo e residuo e nao deve ser usado, e reune o que
    nao pode se perder entre conversas: que tudo e gerado a partir do gerber/ e
    nunca editado a mao, a separacao entre o que o Gerber prova e o que nele nao
    existe, as duas verificacoes com os numeros que elas devem dar, e os dois
    problemas achados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
2026-07-28 Avisa no CLAUDE.md que mais de um agente mexe no repositorio
    Outras IAs vao trabalhar neste projeto, entao o repositorio pode chegar bem
    diferente do que o arquivo descreve. O proprio CLAUDE.md corria o risco de
    virar armadilha: ele lista ferramentas, arquivos e os numeros das verificacoes,
    e qualquer um dos tres envelhece sozinho.
    Passa a separar o que e inventario do que e principio. Inventario -- lista de
    ferramentas, lista de arquivos, numeros das verificacoes -- nao deve ser
    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
2026-07-29 Declara o codigo de terceiros que o repositorio carrega
    Duas coisas aqui nao sao deste projeto e nada dizia isso ao leitor: o three.js
    versionado em web/, e doze simbolos do KiCad embutidos no .kicad_sch.
    O three.js e MIT, e a MIT exige que o aviso de copyright acompanhe as copias.
    O aviso ja vinha preservado dentro do proprio .min.js, entao a exigencia estava
    cumprida na letra -- mas ninguem que abrisse o repositorio saberia de onde
    aquilo veio nem sob qual licenca.
    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
2026-07-29 Define a licenca do projeto como MIT, delimitando o escopo
    Sem arquivo LICENSE valia todos os direitos reservados, o que impedia reuso
    mesmo com o repositorio publico.
    A licenca cobre o que foi criado aqui: os scripts, o visualizador, e os
    desenhos e documentos gerados. Deixa de fora, explicitamente, o gerber/ -- ele
    e o projeto original da placa e pertence a quem a desenhou, esta no repositorio
    como material de origem da engenharia reversa. Licenciar aquilo sob MIT seria
    conceder permissao sobre trabalho de terceiro.
    Pela mesma razao o arquivo anota que o esquematico e os desenhos descrevem a
    placa de outra pessoa: a MIT vale sobre o trabalho de reconstrucao, nao sobre o
    projeto eletrico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
2026-10-27 Acrescenta os simuladores de energia e termico da base
    modulos/energia resolve a divisao de corrente entre celulas e pinos por
    analise nodal do plano de cobre, simula o VRM multifasico com reta de
    carga e SVID, o desarme de uma celula em curto e o balanco da arvore de
    alimentacao. modulos/termico resolve a temperatura da base em regime e no
    transiente, com as fontes de calor de cada peca, do VRM e dos contatos.
    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
2026-10-27 Corrige a netlist ate o verificador separar defeito real de desencontro
    O FPGA ganha transceptores para o DMI e o PCIe 4.0 da CPU, o DIMM ganha
    o sideband I3C do SPD, relogios saem so do gerador, o controle das
    celulas vira hierarquico, os reguladores sao dimensionados pela carga e
    cada provedor declara o que oferece. Os chips tradutores podem ir para
    uma camada de fotonica sob a peca, numa grade de vagas com atribuicao
    otima. O boot so trata como SVID os reguladores na saida de PWM do
    controlador do VRM. Os testes da netlist real usam um fixture comum e
    exigem que ela feche com tradutor sob a peca e rele na celula.
    Claude-Session: htt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
2026-10-28 Poe o banco unificado na base: CPU e GPU na mesma memoria
    O centro do conceito e a memoria compartilhada. Sem CXL nas pecas, a base
    resolve pela porta rapida da GPU, a de memoria:
    - 24 chips GDDR7 (48 GB): cada canal da GPU atende dois chips vizinhos, que
    ela ve como um chip de 32 Gb. No tradutor sob o rank 0 ficam o mux de posse
    (GPU ou ponte) e o seletor de rank, com linha de atraso; o rank 1 usa a
    mesma luz (sombra_de no roteamento).
    - Peca nova PONTE-MEM: para a CPU e um DIMM DDR5 de 48 GB com CL53 no SPD;
    do outro lado, 12 portas GDDR7 ate os mesmos chips. Substitui o DIMM_B.
    - modulos/dados/memoria_unificada.py: mapas de endereco (XOR de bits e resto
    por 3), calibracao por s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
